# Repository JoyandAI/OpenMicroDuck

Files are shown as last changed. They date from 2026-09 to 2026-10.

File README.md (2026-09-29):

# OpenMicroDuck

**一只完全开源的 25cm 双足机器人**

[English](README_en.md) | [中文](README.md)

---

## 这是什么

OpenMicroDuck 是一个**完全开源**的双足机器人平台：一只 25cm 高、不到 1kg 的小鸭子，15 个自由度，能走、会转头、能发声，可以运行强化学习策略。

本项目受** Hugging Face / Pollen Robotics 的 MicroDuck**的启发——感谢他们把这只小鸭子带到世界面前，让全球开发者看到双足机器人可以如此可爱而触手可及；也感谢他们以开放的态度公开训练生态，让我们得以站在他们的肩膀上继续向前。在 MicroDuck 的基础上，我们将把复现过程的硬件图纸、PCB、BOM、软件栈、训练环境——全部公开发布。

它是我们对"技术平权"的一次实践，也是对 MicroDuck 的致谢。

## 当前进展

飞特 HD-1910 的 BAM 执行器参数已更新到我们 fork 的 [microduck_rl](https://github.com/JoyandAI/microduck_rl)（`develop` 分支），可直接查看 [hd1910 参数目录](https://github.com/JoyandAI/microduck_rl/tree/develop/vendor/bam/bam/params/hd1910)。

### 最新视频

[国产方案调通啦 — MicroDuck 复刻·第三话](https://www.bilibili.com/video/BV1GdYC68Enz/)

飞特 HD-1910 已经调通基本流程，更多动作和流畅控制进一步调校中

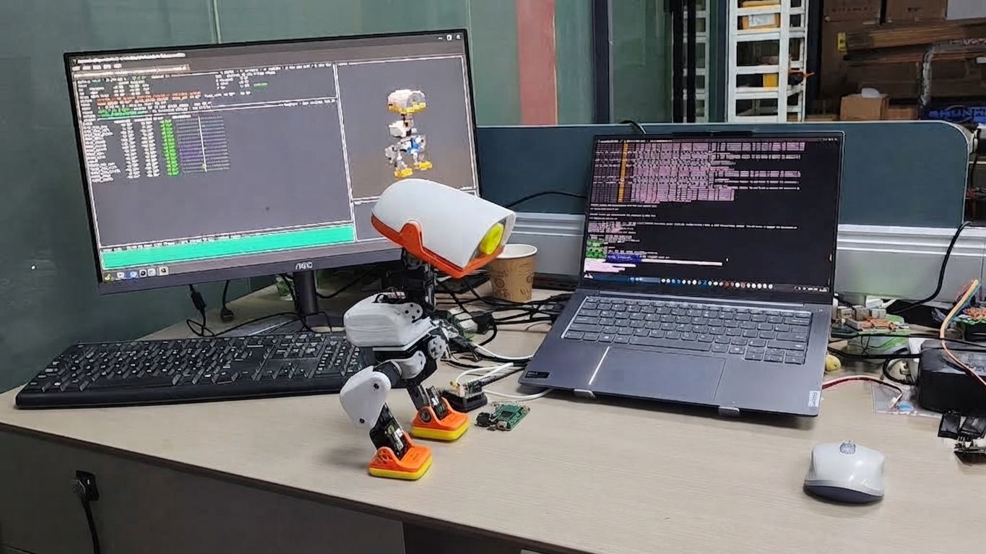
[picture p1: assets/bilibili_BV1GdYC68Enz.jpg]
国产方案调通啦-MicroDuck复刻-第三话


Zero转接HAT板已经回片，测试中...

## 交流群

<p align="center">
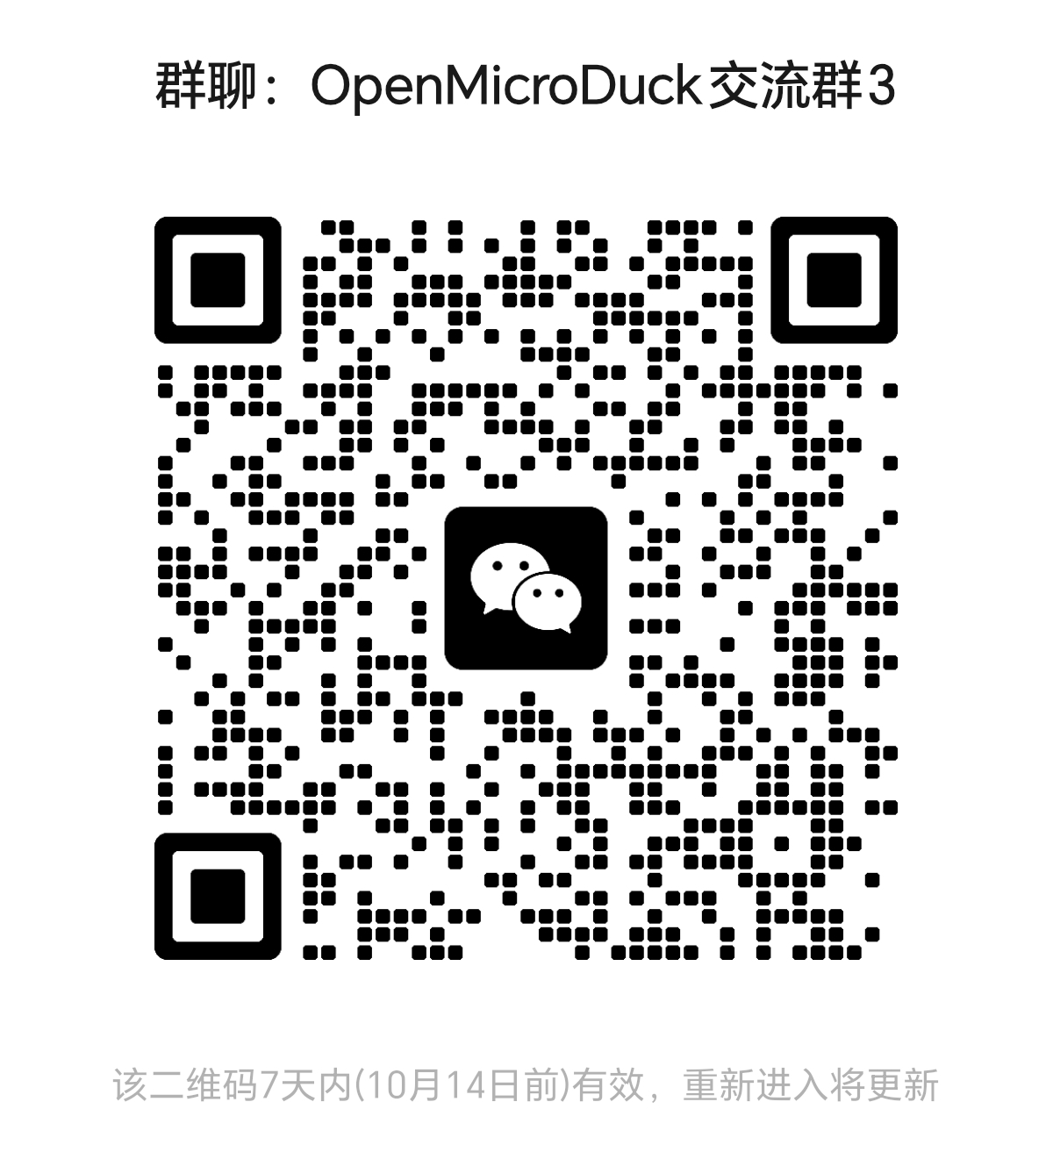
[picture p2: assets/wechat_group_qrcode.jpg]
交流群二维码
  
</p>

## BOM

由于整机集成度比较高，如果完全等所有零配件都ready，再塞进鸭子离线跑，可能要等待比较长的时间。
这里分了两个阶段：

- 第一阶段（桌面调试）：主控和舵机驱动板外置，这样可以由电源适配器供电，主控也可以接显示屏，舵机可由驱动板直接连接PC，方便调试。
- 第二阶段（整机集成）：Zero HAT板和IMU转接板完成之后，再部署已经调试好的模型和软件，完整塞进机器人内部，形成一台完整的整机。

规格、数量、版本差异与结构件清单见 **[docs/bom.md](docs/bom.md)**。

### 桌面调试

| 器件 | 型号 | 规格 | 数量  | 参考单价和链接 |
| ----- | --- | --- | --- | --- |
| 舵机 | **飞特 HD-1910-C001** | 恒力空心杯舵机，4~8.4V，堵转扭矩 12kg·cm | 15  | [118](https://item.taobao.com/item.htm?id=1014620157895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) |
| 主控 | **Radxa ZERO 3W** | RK3566, 2GB RAM，带WiFi, 无eMMC板, 带排针版 | 1 | [309](https://item.taobao.com/item.htm?id=763812025816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) |
| SD卡 | MicroSD/TF卡 | 64GB, A2 | 1 | ~100 |
| IMU模组 | LSM6DSV16X模块 | 支持I2C和SPI接口 | 1 | [49](https://item.taobao.com/item.htm?id=1083871166103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) |
| 摄像头模组 | IMX219摄像头模组 | MIPI FPC排线，500万像素 | 1 | |
| 结构件 | PLA[+TPU] FDM 3D打印  | 有条件的话，脚垫可选用TPU打印 | 1 | - |
| 轴承 | 6700K | 10 x 15 x 3 | 3 | [2](https://item.taobao.com/item.htm?id=1084278550250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) |
| 轴承 | ET2216 | 16 x 22 x 4 | 1 | [3.5](https://item.taobao.com/item.htm?id=1084278550250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) |
| 紧固件 | 螺丝 | M2自攻 | 若干  | |
| 电线 | 特软硅胶线、铁氟龙线 | 30cm | 若干  | |
| 舵机转接线 | | PH2.0转5264 3P转接线（调试用），先用1根PH2.0 3P接驳1根5264 3P线 | 1 | - |
| 麦克风 | | | 2 | |
| 扬声器 | | | 1 | |
| 电池(配重) | 7.4V 3400mAh 2S 锂电池组 | 18650 2串，放电倍率2C，XH2.54 2P公头 | 1 |  [35.8](https://item.taobao.com/item.htm?id=900301752962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) |

### 整机集成

| 器件 | 型号 | 规格 | 数量  | 参考单价和链接 |
| --- | --- | --- | --- | --- |
| 舵机 | **飞特 HD-1910-C001**  | 恒力空心杯舵机，4~8.4V，堵转扭矩 12kg·cm | 15  | [118](https://item.taobao.com/item.htm?id=1014620157895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) |
| 主控 | **Radxa ZERO 3W** | RK3566, 2GB RAM，带WiFi, 无eMMC板, 带排针版 | 1 | [309](https://item.taobao.com/item.htm?id=763812025816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) |
| SD卡 | MicroSD/TF卡 | 64GB, A2 | 1 | ~110 |
| Zero Robot HAT转接板 | | | 1 | |
| IMU_to_servo转接板 | | LSM6DSV16X，带AMP3P-2.0插口 | 1 | |
| 摄像头模组 | IMX219带FPC排线 | 500万像素 | 1 | |
| 结构件 | PLA[+TPU] FDM 3D打印 | 有条件的话，脚垫可选用TPU打印。 | 1 | - |
| 轴承 | 6700K | 10 x 15 x 3 | 3 | [2](https://item.taobao.com/item.htm?id=1084278550250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) |
| 轴承 | ET2216 | 16 x 22 x 4 | 1 | [3.5](https://item.taobao.com/item.htm?id=1084278550250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) |
| 紧固件 | 螺丝 | M2自攻 | 若干  | |
| 麦克风 | | | 2 | |
| 扬声器 | | | 1 | |
| 电池 | 7.4V 3400mAh 2S 锂电池组 | 18650 2串，放电倍率2C，XH2.54 2P公头 | 1 |  [35.8](https://item.taobao.com/item.htm?id=900301752962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) |

### 研发辅助材料

以下是研发调试材料，不是每台机器人必须的BOM

| 器件 | 型号 | 规格 | 数量  | 参考单价和链接 |
| --- | --- | --- | --- | --- |
| 舵机驱动板 | 飞特 URT2串口总线舵机驱动板 | TypeC接口 | 1 | |
| 舵机电源适配器 | 7.5V舵机电源适配器 | 7.5V3A，DC5.5*2.1插头，3C认证 | 1 | - |
| 主控电源适配器 | PD直流电源适配器 | 用TypeC口的PD电源适配器就可以，确认支持5V3A或5V2A | 1 | - |
| 数据线 | USB TypeC->TypeA 或 双头TypeC | 0.5m~1.5m | 1 | |
| MicroHDMI线 | MicroHDMI->HDMI线 | ~1.5m | 1 | |
| 读卡器 | MicroSD卡读卡器 | USB 2.0够用，如果笔记本已经有就不需要了 | 1 | |

## 整机架构

软件与 Microduck 同一条回路：离线 PPO 训出 ONNX，板上 **50 Hz** 执行，契约 **观测 61 维 → 动作 14 维**。硬件换成可公开打样的国产件；换舵机必须重训，官方 ONNX 不能当即插即用步态。

OpenMicroDuck 硬件模块（规划）

选型对照、舵机连线、进程与控制环见 **[docs/README.md](docs/README.md)**（[架构](docs/architecture.md) · [主控](docs/main_controller.md) · [舵机](docs/servo.md)）。

## 路线图

| 里程碑 | 时间 | 目标 |
| --- | --- | --- |
| M1  | 2026-09 | 整机组装，RL 行走验证，桌面调试版确定 |
| M2  | 2026-10 | 整机集成版确定，中英双语教程上线 |
| M3  | 2026-11 ~ | 量产版投产，生态放大：技能包、兼容性持续优化 |

开源项目不拼小批量台数，拼的是复现成功率与开发者体验。每个里程碑公开评审，测试数据与问题清单全量开放。

## 如何参与

任何程度的参与都有意义：

1. **关注** —— Star 本仓库，加入社区（Discord / B 站 / 微信群），见证并传播进展
2. **文档** —— 中英双语教程写作、文档翻译
3. **复现** —— 打印、组装，把公差与干涉问题提 Issue；复现数据是开源硬件最硬的通货
4. **创作** —— 技能包、外观二创、训练管线改进
5. **共建** —— 核心模块 PR，进入维护者委员会，共同决定技术方向

贡献指南见 `CONTRIBUTING.md`（待发布）。

## 为什么做这个项目

**让门槛再低一点。** 双足机器人的核心技术并没有想象中遥远，但一套进口舵机动辄数千元、关键结构闭源、教程零散——把太多人挡在了门外。我们把每个环节拆开、验证、用高性价比的国产供应链重新实现，然后把一切公开：主控只要求 RK3566 同级算力，电池组安全、可拆解，结构件一台 3D 打印机就能做出来。

**让生态再大一点。** 我们希望更多供应链厂商参与进来——舵机、主控、电池、3D 打印与注塑结构件。兼容性矩阵公开，任何厂商的同类器件都可以来适配。竞争发生在开放的标准上，受益的是整个生态。

**让创意再多一点。** 一只鸭子能做什么，不该由我们定义。换一个皮肤甚至换一种形态、写一个新技能、改一套步态、接一颗传感器——我们期待看到更多开发者的二创、以及我们根本想象不到的玩法。你创造的不只是一台机器鸭，而是下一个有意思、有价值产品的起点。

## 许可证

| 内容 | 许可证 |
| --- | --- |
| 硬件图纸、PCB、BOM | CERN-OHL-S |
| 软件栈、训练环境 | Apache-2.0 |
| 教程与文档 | CC BY-SA |

## 致谢

本项目受 Hugging Face / Pollen Robotics 的 MicroDuck启发，并复用了其公开的训练生态。再次感谢 MicroDuck 团队的开创性工作与开放精神——没有他们，就没有这个项目。OpenMicroDuck 是独立的社区开源项目，与 Hugging Face、Pollen Robotics 无隶属关系。

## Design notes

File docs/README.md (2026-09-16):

# OpenMicroDuck 文档

本目录是硬件与软件规划的入口。当前选型：

| 项目  | 当前选择 | 详细文档 |
| --- | --- | --- |
| 架构  | 几何与控制契约对齐 Microduck；供应链换成可公开打样的国产件 | [architecture.md](architecture.md) |
| 主控  | **Radxa ZERO 3W**（RK3566，≥1 GB，有 eMMC 更好） | [main_controller.md](main_controller.md) |
| 舵机  | **飞特 HD-1910-C001** × 15 | [servo.md](servo.md) |
| BOM | 桌面调试版 / 整机集成版器件清单；结构螺丝与 3D 打印件 | [bom.md](bom.md) |

条目索引与外部链接见 [reference.md](reference.md)。

证据分级与各篇正文相同：**官方** / **源码还原** / **规划** / **未定**。本文是摘要，数字与接口以对应长文为准。

---

## 1. 架构 — [architecture.md](architecture.md)

软件与硬件如何拼在一起：策略在哪训练、模型长什么样、板载如何采样 / 推理 / 驱动电机与扬声器。

**软件架构不区分 Microduck 与本仓库。** 两边走同一条 sim-to-real 回路：离线训出 ONNX，板上 50 Hz 闭环执行。差别在执行器品牌、电池、哪些 PCB 开源。

### 软件（通用）

- 训练不在机器人上：`microduck_rl` 用 mjlab（MuJoCo Warp）+ PPO；执行器模型（BAM）和域随机化决定能否上真机。
- 运动策略是 **ONNX**，契约 **观测 61 维 → 动作 14 维 @ 50 Hz**。嘴是第 15 轴，由上层逻辑开合，不进策略。
- 摄像头和 8×8 ToF **不进入**标准行走策略；感知侧只把几十字节特征喂给行为层。
- 板载七个守护进程 + `robotctl`，Unix socket 上 JSON-RPC。**只有** `robotd` **能写电机。**
- 走路在 CPU 上跑 ONNX Runtime；NPU 留给视觉检测，不进平衡环。

### 硬件（规划）

目标：25 cm、15 DoF、50 Hz、61/14；机械图纸、PCB、BOM 按 CERN-OHL-S 发布。

OpenMicroDuck 硬件模块（规划）

| 模块 | 规划 |
| --- | --- |
| 计算主控 | RK3566 同级；当前落地先用 Radxa ZERO 3W，见下文 |
| 舵机 ×15 | 飞特 TTL 半双工、带位置/速度/电流反馈；当前落地选 HD-1910-C001 |
| 机身 IMU | 自制 `imu_to_servo`，挂在舵机总线上，从机 ID 200 |
| 头部 IMU | I²C 辅助模组，**不进** 50 Hz 平衡环 |
| 相机 / ToF | CSI 模组 + 8×8 DToF（I²C） |
| 电池 | 当前用2S 18650电池组7.4V复现 |

换舵机或改质量分布之后，官方 ONNX **不能当即插即用步态**；要在 `microduck_rl` 里按新执行器重训，并保持 `obs[61] → act[14]`。

---

## 2. 主控 — [main_controller.md](main_controller.md)

**当前选择：Radxa ZERO 3W。**

与官方 Microduck 开发栈差异最小：设备树 `compatible = "radxa,zero-3w"`，overlay、NPU 脚本、HAT 针脚都按这块板写过。优先买 **≥1 GB RAM、有 eMMC** 的那档（官方机是 1 GB + 32 GB eMMC）。

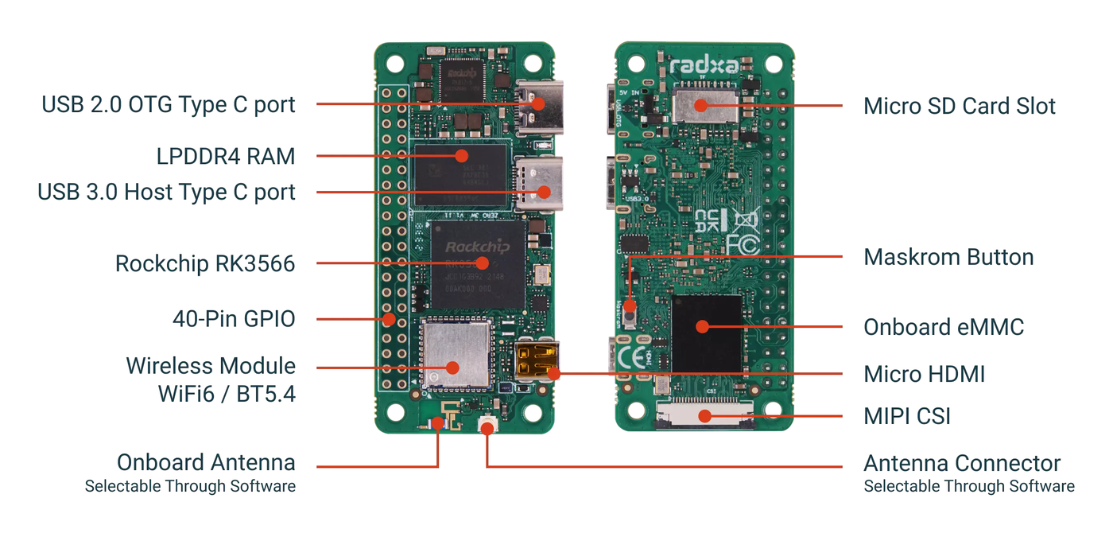
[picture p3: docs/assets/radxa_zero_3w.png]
Radxa ZERO 3W


*图：正反面接口。来源：[Radxa ZERO 3 文档](https://docs.radxa.com/zero/zero3)。*

| 项目 | ZERO 3W |
| --- | --- |
| 尺寸 | 65 mm × 30 mm（Pi Zero 同外形） |
| SoC | RK3566，四核 A55 @ 最高 1.6 GHz |
| AI | NPU 0.8 TOPS（INT8）；走路不用，视觉检测用 |
| 内存 / 存储 | 1–8 GB LPDDR4；可选 eMMC 或 microSD |
| 无线 | Wi-Fi 6 + BT 5.4 |
| 和鸭子相关的口 | UART2 → 舵机总线；I²C3 → ToF / codec；MIPI CSI → 相机；I²S → 喇叭 |

验收三件事：50 Hz 跑完 ORT 且 CPU 有余量；HAT 上同时拿出 UART + I²C + I²S（3.3 V）；有可用 CSI。

同系列 **ZERO 3E** 用网口换掉无线，除非外挂 Wi-Fi / BT，否则不合适。Armbian 默认在 UART2 开 `serial-getty`，不 mask 会占死舵机总线。

详细文档还列了其它 RK3566 模组、CM4 核心板、RK3568、进迭时空 K1 等平替路径；那些是缺货或改载板或升级时的备选，**不是当前默认件**。

---

## 3. 舵机 — [servo.md](servo.md)

**当前选择：飞特 HD-1910-C001**（产品页 / 对照表亦作 HD-1910；外形图文件名为 `HD-1910M-C001`）。

Microduck 运行时按 Dynamixel XL330-M288-T 说话。HD-1910-C001 是飞特为开源小鸭做的预售款：磁编码、恒力、TTL 菊花链，电压 **5–8.4 V**，比 XL330 的 5 V 上限更适合 2S 锂电 / 18650。换型号必须 **重训** 策略。

| 项目 | HD-1910-C001（当前选择） | XL330-M288-T（官方基线） |
| ----- | --- | --- |
| 重量 | 21 ± 2 g | 18 g |
| 尺寸 mm | 34 × 20 × 23 | 20 × 34 × 26 |
| 堵转扭矩  | 12 kg·cm @6V（1.18 N·m） | 0.52 N·m @ 5 V |
| 额定扭矩  | 3.0 kg·cm（0.29 N·m） | 未给 |
| 空载转速  | 110 rpm | 103 rpm @ 5 V |
| 供电 | **4–8.4 V** | 3.7–6.0 V（推荐 5 V） |
| 接口 | AMP2.0-3P | JST 3P TTL |
| 协议 | 飞特 TTL 半双工 | Dynamixel 2.0 |
| 反馈 | 负载 / 位置 / 速度 / 电压 / 电流 / 温度 | 位置 / 速度 / 电流 / PWM / 电压 / 温度 |

总线规划与官方运行时对齐，便于沿用观测布局（嘴仍是策略外的第 15 轴）。板上 UART 与舵机都应跑在 **1 Mbps**；出厂若不是这个波特率，要在初始化里改过去。

### 舵机连线

15 颗 HD-1910-C001 + 机身 IMU 挂在 Zero HAT 引出的同一条 TTL 半双工总线上，菊花链分叉如下。

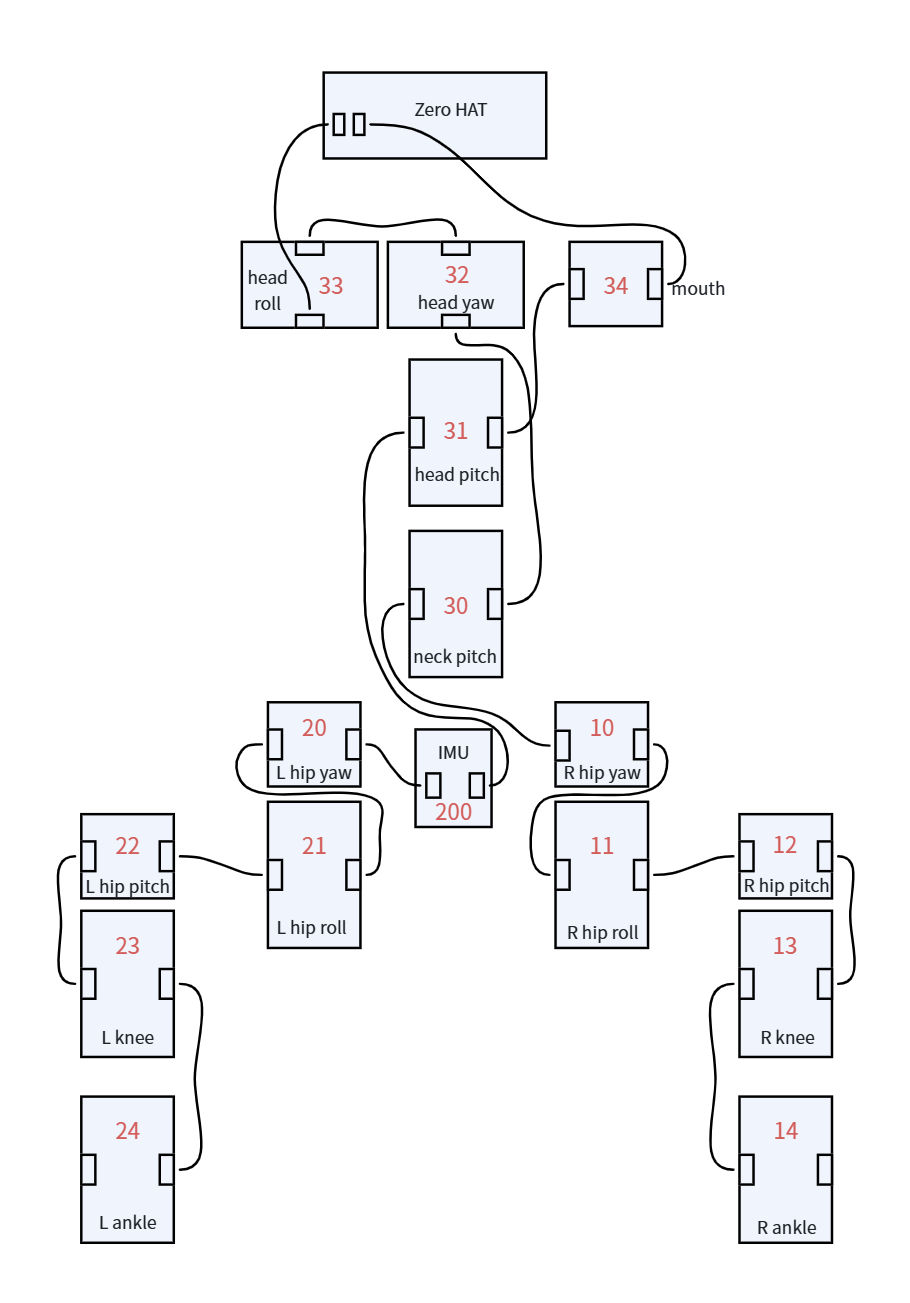
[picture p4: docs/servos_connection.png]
舵机之间的连接关系


```text
Zero HAT
  ├─ 34 mouth
  └─ 33 head_roll → 32 head_yaw → 31 head_pitch → 30 neck_pitch
                                              ├─ 20 L hip yaw → 21 roll → 22 pitch → 23 knee → 24 ankle
                                              ├─ 10 R hip yaw → 11 roll → 12 pitch → 13 knee → 14 ankle
                                              └─ 200 IMU（跨接在左右髋之间）
```

ID 规划：

```text
右腿          10 right_hip_yaw · 11 right_hip_roll · 12 right_hip_pitch · 13 right_knee · 14 right_ankle
左腿          20 left_hip_yaw  · 21 left_hip_roll  · 22 left_hip_pitch  · 23 left_knee  · 24 left_ankle
颈 / 头 / 嘴  30 neck_pitch    · 31 head_pitch     · 32 head_yaw        · 33 head_roll  · 34 mouth
机身 IMU      200
```

宇树 YS-342026-S288、伺泰威 ED330、飞特 HL-2915 等对照见 [servo.md](servo.md) §3；那些是候选，**不是当前默认件**。

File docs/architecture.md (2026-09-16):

# OpenMicroDuck / Microduck 架构

本文整理软件与硬件如何拼在一起：策略在哪训练、模型长什么样、板载如何采样 / 推理 / 驱动电机与扬声器，以及各模块靠什么接口通信。

**软件架构不区分 Microduck 与本仓库规划。** 两边走同一条 sim-to-real 回路：离线训出 ONNX，板上 50 Hz 闭环执行。硬件选型、电源与开源边界不同，见后两节。

证据分级：

| 标记 | 含义 |
| --- | --- |
| **官方** | 产品页、新闻稿，或 `pollen-robotics/microduck` / `microduck_rl` 源码与设计文档 |
| **源码还原** | 运行时写死的设备路径、I²C 地址、寄存器；社区据此还原，非官方 BOM |
| **规划** | 本仓库 README 与规划文档 |
| **未定** | 公开材料互相矛盾，或量产件尚未冻结 |

条目来源见 `[reference.md](reference.md)`。Microduck 机械 / 整机电控并未作为开源硬件发布；HAT 板除外。

---

## 1. 软件架构（通用）

整条链路是「离线训、板上跑、意图进、安全层出」。摄像头图像和 8×8 ToF **不进入**标准行走策略；它们走感知侧，只把几十字节的特征喂给行为层。

软件总览：离线训练与板载执行

### 1.1 训练在哪做

训练不在机器人上。官方仓库 `[microduck_rl](https://github.com/pollen-robotics/microduck_rl)` 用 **mjlab（MuJoCo Warp）+ PPO**。需要 CUDA；没有本地 GPU 时可用 Hugging Face Jobs。

训练里真正决定能否上真机的，是执行器模型而不是视觉：

- **BAM M6**：按 Dynamixel XL330 的电压控制律、反电动势、库仑 / Stribeck / 负载相关摩擦建模。
- **域随机化**：电池电压、负载压降、指令延迟、摩擦系数。
- **回差变体**：每个关节串联 ±1° 齿轮间隙；观测读的是编码器侧（间隙之后），与真机一致。

任务按技能拆开（走、站、起坐、地面拾取、踢球、翻滚、轮滑等），但观测宽度统一，所以运行时可以热切换网络。社区可在 Mac / DGX Spark / Isaac Lab / Genesis 上复训，契约仍是同一套 61 / 14。

仿真网页沙盒（Hugging Face Space）用 MuJoCo WASM + onnxruntime-web，同样 50 Hz 跑真实策略，用来验图、不替代训练。

### 1.2 生成的模型是什么样的

运动策略是 **ONNX**，不是 PyTorch 权重直接上机。导出脚本把观测归一化烘焙进图；手转 checkpoint 会让策略看到未归一化输入。

契约（加载时校验，形状不对则拒绝）：

| | 维数 | 内容 |
| --- | --- | --- |
| 观测  | **61** | `gyro(3)` + `projected_gravity(3)` + `joint_pos(14)` + `joint_vel(14)` + `last_action(14)` + `command(13)` |
| 动作  | **14** | 14 个关节目标；**嘴舵机不在策略里** |
| 频率  | **50 Hz** | 与控制环同一拍 |

`command(13)` = 速度指令 `vx, vy, vyaw`（3）+ 头目标 4 + 身体姿态 6。身体块里 x / y / yaw 在训练中未绑定，标称全零。

嘴（第 15 个舵机）由上层逻辑开合（拾取、合唱口型、特雷门等），动作向量写回 15 槽时该位置保持 0。

官方策略按槽位发布（走、站、起坐、左右踢、地面拾取、翻滚、轮滑等），Hub 仓库一份 `.onnx` + `manifest.json`（观测/动作维、`model_api`、机型兼容性）。板上三个来源填同一个槽：官方组件、社区 Hub、本地路径。

视觉检测是另一类模型：`duck_detector` 训出的 **INT8** `.rknn`（例：YOLO11n 320×320），跑在 RK3566 NPU 上，**不**进 50 Hz 运动环。仓库对外 404，板上路径设计为挂在 `mediad` 里。

音频不是神经网络：每台机器用 SoC 序列号生成确定性「性格」种子，合成一套叫声 bank（chirp / greet / coo 等），不是 TTS。

### 1.3 模型在哪运行

运动 ONNX 在板上由 `robotd` **用 ONNX Runtime** `dlopen` **推理**，每拍一次。ORT 是板级依赖，不打进发布包。

感知在传感器旁边：

| 模型 / 功能 | 进程 | 加速器 |
| --- | --- | --- |
| 运动策略 `.onnx` | `robotd` | CPU（ORT） |
| 鸭子检测 `.rknn` | 设计落在 `mediad` | NPU 0.8 TOPS |
| 麦克风宠物检测（约 20 KB CNN，40-band log-mel） | `robotd` 工作线程 | CPU |

原则：**给控制环的是特征，不是帧。** `robotd` 不订阅 640×480 RGB；它读「球在 (x,y)」「附近有鸭子」这类几十字节、10–30 Hz 的快照。帧卡在 `mediad`，控制环卡不住。

### 1.4 板载进程如何拼在一起

七个守护进程 + 一个 CLI，Unix socket 上 **JSON-RPC 2.0（NDJSON，一行一个对象）**。`systemd` 管生命周期。

板载进程：同一套 API，多种传输

| 进程 | 拥有 | 监听 | 对外 |
| --- | --- | --- | --- |
| `robotd` | 电机、机身 IMU、策略、安全、健康 | `/run/robotd.sock` | Dynamixel（或兼容）总线 |
| `configd`  | Wi-Fi、名字、配对 PIN、手柄绑定 | `/run/configd.sock` | BlueZ / NetworkManager（D-Bus） |
| `updaterd` | 发布包验签、原子切换、回滚 | `/run/updaterd.sock`  | GitHub、`systemctl`、`robot.health` |
| `btd` | 无状态，BLE 门面 | GATT | 转发给 `robotd` / `configd` / `updaterd` |
| `padd` | 无状态，手柄 → 意图 | `/run/padd/pad.sock`  | `robotd` |
| `mediad` | 摄像头、麦克风、编码、WebRTC、远端网关 | TCP `:8080` / `:8443` | 转发给上述服务 |
| `tofd` | 头上 ToF | `/run/tofd/tof.sock`  | HAT 上的 I²C |
| `robotctl` | CLI | — | 所有 socket |

不变量：

1. **只有** `robotd` **能写电机。** 客户端发意图（「这个速度走」「看那边」「坐下」），安全层决定是否执行。
2. `configd` **/** `updaterd` **/** `btd` **在** `robotd` **死掉时仍可用** —— 这是恢复路径。
3. **控制环不对其他服务做同步 RPC。** 跨进程读是 last-value-wins 缓存。
4. **控制面走 socket；视频/音频帧不走 socket。** 真要跨进程传帧，才用 shm / dmabuf。

远端同一套 API、多种传输：BLE（子集）、Unix socket、WebSocket（给 LLM：按需 JPEG，不要 30 fps）、WebRTC datachannel（遥操）。WebRTC 里 `control` 可靠有序，`teleop` 不可靠无序 —— 重传 80 ms 前的摇杆指令比丢掉更糟。

### 1.5 一拍里发生什么（传感器 → 决策 → 电机）

50 Hz，每拍两次总线事务，每秒一次慢采样：

50 Hz 控制环：一拍里的数据流

每秒另读电压 / 温度（寄存器 144–146）。电压是 15 个舵机供电的平均（没有电量计）；温度按关节上报，取最热的那个名字。

摔倒分两层：投影重力 mag 过阈值并 debounce，只用于报告；`limp_fall` 用陀螺预测即将着地，短暂接管关节、卸力、再交回站立策略。摔倒本身不禁止 `enable` / 技能 —— 躺着的时候更需要这些调用能用。

### 1.6 各传感器如何进软件

| 数据 | 谁读 | 频率 | 进运动策略？ |
| --- | --- | --- | --- |
| 关节位置 / 速度 / PWM / 电流 | `robotd` 一次 `sync_read` | 50 Hz | 是（14 关节） |
| 机身 IMU：陀螺 + SFLP 四元数 | 同一趟 `sync_read`（总线 ID 200） | 50 Hz | 是（gyro + projected gravity） |
| 电池电压、舵机温度 | `robotd` 慢采样 | 1 Hz | 否（电压自适应缩放可选） |
| 8×8 ToF | `tofd` → socket 订阅 | ~15 Hz | 否；特雷门、避障、高层行为用 |
| 摄像头 | `mediad`（ISP + MPP H.264） | 默认 720p30 | 否；检测结果作特征 |
| 麦克风 | codec → ALSA；`mediad` 推流，`pet-detect` 另读 | 音频速率 | 否 |
| 头部 IMU | 产品规格有；当前运行时控制环不用 | — | 否 |
| SoC 温度 | `robotd` 读 sysfs | 1 Hz | 否 |

里程计在环内算：足端接触 + IMU 航向。没有磁力计，航向会漂，调用方按相对运动用。

### 1.7 扬声器如何发声

声音不经策略网络。

1. 安装时 `sounds ensure-bank` 用 SoC 序列号生成种子，渲染该机独有的叫声 bank。
2. `robotd` 里 `sound.rs` 拉起一个 `aplay` 子进程；codec 的 PCM 独占，新叫声杀掉旧的。
3. 播放走 ALSA 设备（开发路径上是 `plughw:aic3104`）。喇叭挂在 codec 的 line-out（LEFT_LOP / RIGHT_LOP）。
4. 合唱：多机 BLE 信标选最低 ID 当指挥；`btd` 只搬信标，不决策。合唱会动嘴和头，所以默认关闭。
5. 特雷门：`tofd` 的深度 → 音高 + 嘴开度，50 Hz 环只采样、不等待。

WebRTC 会话可以双向带麦克风和喇叭，用于遥在；本地叫声和远端音频抢同一条 PCM。

---

## 2. 硬件模块架构

两边都是：RK3566 同级 Linux 板 + 扩展板（电源 / 音频 / I²C）+ 一条半双工舵机总线 + 头上的相机 / ToF。差别在执行器品牌、电池、哪些 PCB 开源。

### 2.1 我们规划的架构（OpenMicroDuck）

目标：几何与控制契约对齐 Microduck（25 cm、15 DoF、50 Hz、61/14），供应链换成可公开打样、可替代的国产件。机械图纸、PCB、BOM 按 CERN-OHL-S 发布。

规格（规划，未冻结）：

| 项目  | 规划 |
| --- | --- |
| 整机  | 25 cm / ≤1 kg |
| 自由度 | 15（腿 5×2 + 头颈 4 + 鸭嘴 1） |
| 舵机  | 15 × **Feetech 协议平替**（TTL 半双工、带位置/速度反馈） |
| 主控  | **RK3566 同级**（不绑定某一款模块，兼容性矩阵另发） |
| 电池  | **可拆 18650 电池组** 2S 7.4V, 3S 12V |
| 结构  | 3D 打印（FDM / 光固化）+ 钣金 |
| 控制  | 50 Hz 板载策略环；训练仍用 MuJoCo / PPO |

OpenMicroDuck 硬件模块（规划）

#### 模块与接口（规划）

| 模块 | 规划形态 | 物理接口 | 协议 | 备注 |
| --- | --- | --- | --- | --- |
| 计算主控 | RK3566 同级 SBC | 40-pin、CSI、UART、USB-C | Linux 外设 | 不绑定 Radxa；要能跑 50 Hz ORT + 可选推流 |
| 舵机 ×15 | Feetech 平替 | 3 线：GND / 电源 / DATA | 厂家 TTL 总线（与 Dynamixel 类似的半双工包） | 换执行器必须 **重训** 策略；官方 ONNX 不能当 bit-exact 用 |
| 机身 IMU | `imu_to_servo` 自制板 | 挂在舵机总线上 | 规划对齐官方从机：ID 200、1 Mbps、寄存器 124 起 12 字节（陀螺 i16 + 四元数 fp16） | MCU + LSM6DSV16X（SFLP）+ 半双工 PHY；控制环不在主机上做融合 |
| 头部 IMU | 小 I²C 模组 | 4 针：GND / 3V3 / SDA / SCL | I²C ≤400 kHz | **不进平衡环**；与 ToF 共总线，注意地址 |
| 图像传感器  | CSI 摄像头模组 | MIPI CSI（控制常走 I²C `0x10` 一类） | CSI-2 + I²C | 具体传感器未钉死；软件侧按「感知在 `mediad`」接 |
| DToF | 8×8 多区 ToF | Qwiic / Stemma 类 3.3 V I²C | I²C，常见地址 `0x29` | VL53L5CX / L8CX 一类；`tofd` 发布矩阵 |
| 麦克风 | MEMS，经 codec 或板载 | I²S 数据 + I²C 控制 | ALSA | 可与官方 HAT 路线兼容，或换国产 codec |
| 扬声器 | 小喇叭 | codec line-out / 功放 | I²S → 模拟 | `aplay` 播预渲染 bank |
| 电源 | 18650 可拆组 | HAT 作配电 | — | 与官方 NP-F550 不同；需自管充电、过放、舵机供电轨 |

舵机 ID 规划与官方运行时对齐，便于沿用观测布局（嘴仍是策略外的第 15 轴）：

```text
右腿          10 right_hip_yaw · 11 right_hip_roll · 12 right_hip_pitch · 13 right_knee · 14 right_ankle
左腿          20 left_hip_yaw  · 21 left_hip_roll  · 22 left_hip_pitch  · 23 left_knee  · 24 left_ankle
颈 / 头 / 嘴  30 neck_pitch    · 31 head_pitch     · 32 head_yaw        · 33 head_roll  · 34 mouth
机身 IMU      200
```

##### 桌面调试阶段
桌面调试阶段的硬件连接关系图
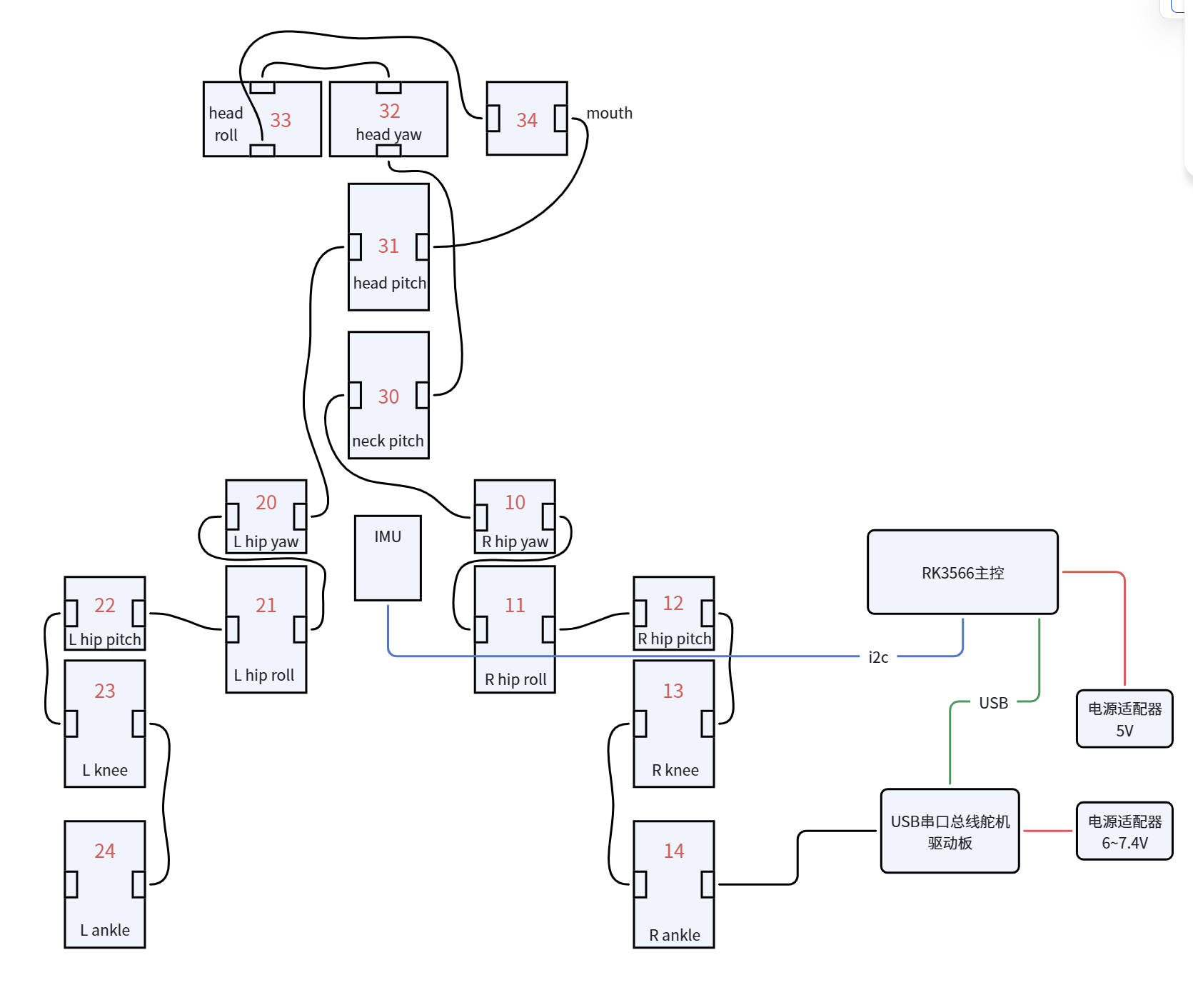
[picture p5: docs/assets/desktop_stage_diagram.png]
桌面调试版硬件连接关系


##### 整机集成阶段
整机集成阶段的硬件连接关系图
整机集成版舵机之间的连接关系

HAT 需要至少三件事：舵机半双工方向电路、电池配电、I²C/I²S 外设。官方 `[elec_RPI_Robot_HAT](https://github.com/pollen-robotics/elec_RPI_Robot_HAT)` 已开源且标明可驱动 Dynamixel **或 Feetech**（线序可能要改），可作第一版参考，再按 18650 与国产件重画。

与官方栈的关系：主控同级、总线从机行为对齐时，可直接跑 Apache-2.0 的 `robotd` 一族。Feetech 寄存器 / 波特率 / 力矩曲线不同，则要在 `RobotIo` 下加驱动，并用 `microduck_rl` 按新 BAM（或实测执行器）重训。

---

### 2.2 推测的 Microduck 架构

产品规格只钉到「RK3566、15 电机、相机、LiDAR、双 IMU」。下面到芯片 / 连接器这一层，来自 **公开运行时、设备树、HAT 开源仓** 的还原，**不是** Pollen 发布的量产 BOM。量产前仍可能改。尚未有可核对的零售机拆解。

整机（官方）：高 25 cm、宽 14 cm、<800 g；15 DoF；50 Hz 策略环；电池 NP-F550 2600 mAh；Wi-Fi + 蓝牙；NFC 双天线（头 + 喙，控制器未公开）。

Microduck 硬件模块（源码还原，非官方 BOM）

#### 模块、接口、协议

| 模块 | 推测 / 还原型号 | 接口 | 协议 | 证据 |
| --- | --- | --- | --- | --- |
| 计算主控 | **Radxa Zero 3W**（RK3566，四核 A55 + Mali-G52 + NPU 0.8 TOPS） | CSI、40-pin、UART2、板载 Wi-Fi/BT | Linux | 设备树 `compatible = "radxa,zero-3w"`；产品规格钉 SoC / 1G+32G |
| 舵机 ×15 | **ROBOTIS Dynamixel XL330**（社区多指向 M288-T 一类） | 3 线 TTL：GND / VDD / DATA | **Protocol 2.0，1 Mbps** | `robotd` 总线文档；`rustypot` 寄存器表 |
| 半双工 PHY | 在 HAT 上 | UART TX/RX → 单线 DATA | 硬件自动换向（源码无方向 GPIO） | HAT README：TTL 与 485 都做了 |
| 机身 IMU | **ST LSM6DSV16X** 在自制 `imu_to_dxl` v2 | 与舵机同一 UART | DXL 从机 **ID 200**；`sync_read` 地址 124、12 字节 | `duck-control` IMU 代码。板子原理图 **未开源** |
| HAT 上第二 IMU | **Bosch BMI088** | I²C `0x19` / `0x68` | I²C | 焊着，源码写 unused / dormant |
| 头部 IMU | 产品规格「头 + 身体各一」 | 未公开 | 未进入当前 `robotd` 控制环 | 官方规格 vs 源码「One IMU, one code path」—— **未对齐** |
| 图像传感器 | **Sony IMX219**（Pi Camera v2 路径） | MIPI CSI + I²C `0x10` | CSI-2；1080p30 传感器模式，ISP 缩到 720p30 | `mediad` / 设备树。量产镜头 **未冻结**（新闻稿） |
| DToF | **VL53L5CX 或 VL53L8CX**（8×8） | HAT Stemma J5，I²C `0x29` | I²C，上电要灌约 90 KB 固件 | `tofd`；两代芯片源码都支持，量产哪颗 **未钉** |
| 音频 codec | **TI TLV320AIC3104** | I²C `0x18` 控制 + **I²S3** 数据；MCLK 12 MHz | I²C + I²S，ALSA 卡名 `aic3104` | 设备树 overlay |
| 麦克风 | HAT 板载 MEMS，走 Mic3R | 模拟 → codec PGA | — | 具体料号未公开 |
| 扬声器 | 接 codec LOP | 模拟 | — | 料号未公开 |
| NFC | 双天线：头 + 喙 | 未公开 | 未公开 | 仅产品规格；运行时源码无提及 |
| 电池 | **Sony NP-F550**，2S，标称 7.2 V | 经 HAT 配电 | 无电量计；电压 = 舵机回报的总线电压 | 官方规格 + 运行时注释。零售 XL330 额定 3.7–6.0 V，与 2S 直供 **如何匹配尚未被量产机证实** |

舵机 ID（官方控制环）：

```text
imu_to_dxl    200
右腿          10 right_hip_yaw · 11 right_hip_roll · 12 right_hip_pitch · 13 right_knee · 14 right_ankle
左腿          20 left_hip_yaw  · 21 left_hip_roll  · 22 left_hip_pitch  · 23 left_knee  · 24 left_ankle
颈 / 头 / 嘴  30 neck_pitch    · 31 head_pitch     · 32 head_yaw        · 33 head_roll  · 34 mouth
```

`imu_to_dxl` 12 字节块（与 15 个舵机同一趟读，主机不做融合）：

| 偏移 | 内容 |
| ---- | --- |
| 0–5  | 陀螺 x/y/z，`i16` LE，±500 dps |
| 6–11 | SFLP 四元数 x/y/z，IEEE binary16；`w` 在主机用 `√(1−x²−y²−z²)` 补 |

HAT 上 I²C3 占用 40-pin 的 3/5。Radxa 原厂把同一控制器的 M1 给了 USB-C PD（FUSB302）；官方 overlay 改到 M0 后 **失去 PD 协商**，普通 5 V 充电仍可用。Armbian 默认在 UART2 开 `serial-getty`，不 mask 就会把整条舵机总线占死。

#### 和「双 IMU」的关系

新闻稿写身体、头部各一颗 IMU。源码控制环只认总线上的 LSM6DSV16X。HAT 的 BMI088 明确休眠。头部那颗更像交互 / 头姿辅助，或量产与开发板不一致。复刻平衡环时，**不要**把第二颗 IMU 当成 50 Hz 观测的一部分。

#### 开源边界（官方立场）

| 开源 | 未作为开源硬件发布 |
| --- | --- |
| 板载软件（Apache-2.0） | 可编辑机械 CAD、整机装配文档  |
| `microduck_rl` 与 ONNX 策略 | `imu_to_dxl` 原理图  |
| 仿真 MJCF + 训练用 STL | 量产 BOM、线束图 |
| **RPI Robot HAT**（KiCad / Gerber / BOM） | NFC 控制器；部分传感器量产料号 |

---

## 3. 对照摘要

| | OpenMicroDuck（规划） | Microduck（公开材料 + 源码还原） |
| --- | --- | --- |
| 软件 | 同一套：PPO 离线训 → ONNX → 板上 50 Hz `robotd` | 同左（官方实现） |
| 主控 | RK3566 **同级**，不绑模块 | 产品：RK3566；开发板还原为 Radxa Zero 3W |
| 舵机 | Feetech 平替 | Dynamixel XL330 |
| 机身 IMU | 自制 `imu_to_servo`，行为对齐 ID 200 | 同结构，原理图未开源 |
| 头部 IMU | I²C 辅助模组，不进控制环 | 规格有；运行时未用 |
| ToF / 相机 | 同角色（I²C 8×8 + CSI） | VL53L5/8CX + IMX219 路径 |
| 电池 | 18650 可拆组 | NP-F550 |
| 硬件开源 | 图纸 / PCB / BOM 全公开 | 仅 HAT + 软件；整机不称开源硬件 |

换舵机或改质量分布之后，官方 9 个 ONNX 不能当即插即用步态；要在 `microduck_rl` 里按新执行器重训，并保持 `obs[61] → act[14]`，才能继续热切换技能。

---

## 4. 主要来源

- 官方运行时架构：[https://github.com/pollen-robotics/microduck/blob/main/docs/design/architecture.md](https://github.com/pollen-robotics/microduck/blob/main/docs/design/architecture.md)
- 控制环与总线：[https://github.com/pollen-robotics/microduck/blob/main/docs/design/robotd-design.md](https://github.com/pollen-robotics/microduck/blob/main/docs/design/robotd-design.md)
- 策略通道：[https://github.com/pollen-robotics/microduck/blob/main/docs/design/policy-channel-design.md](https://github.com/pollen-robotics/microduck/blob/main/docs/design/policy-channel-design.md)
- 训练：[https://github.com/pollen-robotics/microduck_rl](https://github.com/pollen-robotics/microduck_rl)
- HAT：[https://github.com/pollen-robotics/elec_RPI_Robot_HAT](https://github.com/pollen-robotics/elec_RPI_Robot_HAT)
- 产品规格：[https://pollen-robotics.com/microduck/press-kit/](https://pollen-robotics.com/microduck/press-kit/)
- 条目索引：`[reference.md](reference.md)`

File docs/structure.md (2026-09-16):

# OpenMicroDuck 结构说明

> 优化结构版本：**v0.1**

本仓库内的结构经过修改以适配舵机 **HD1910**，与之结构相同的还有 **HL2909** 舵机。同时优化了部分结构，让它更适合 3D 打印、也更加稳定。

## 打印与装配

- 使用 Bambu Studio 直接打印已经摆盘好的 `cad/openmicroduck.3mf` 即可。
- 装配参考文件：`cad/openmicroduck-assembly-opt.stl`。
- 散件文件：`cad/psrts`。
- BOM 表（含结构件与电器件）：[bom.md](bom.md)

## 结构差异（舵机）

MicroDuck 上使用的舵机大部分要拆掉副舵盘来安装，且使用 XL330舵机，与本仓库兼容的舵机在拆掉副舵盘后有明显的结构差异：

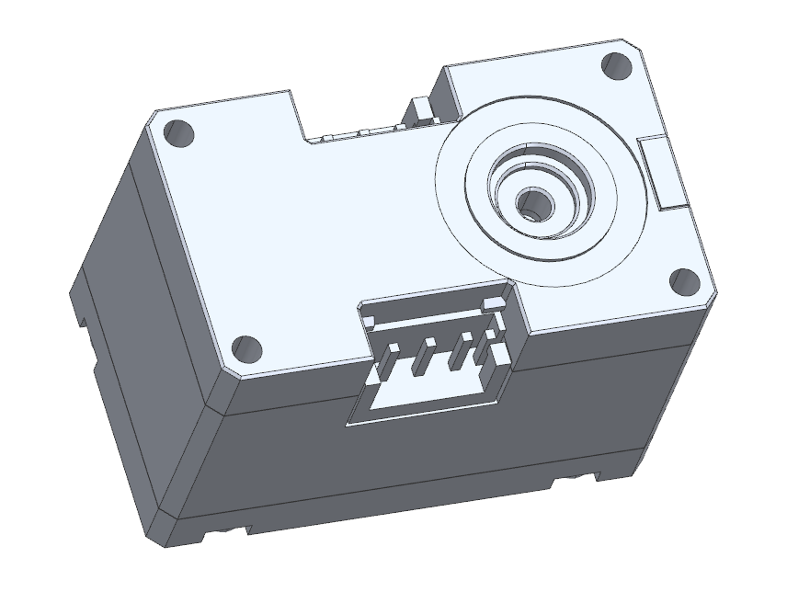
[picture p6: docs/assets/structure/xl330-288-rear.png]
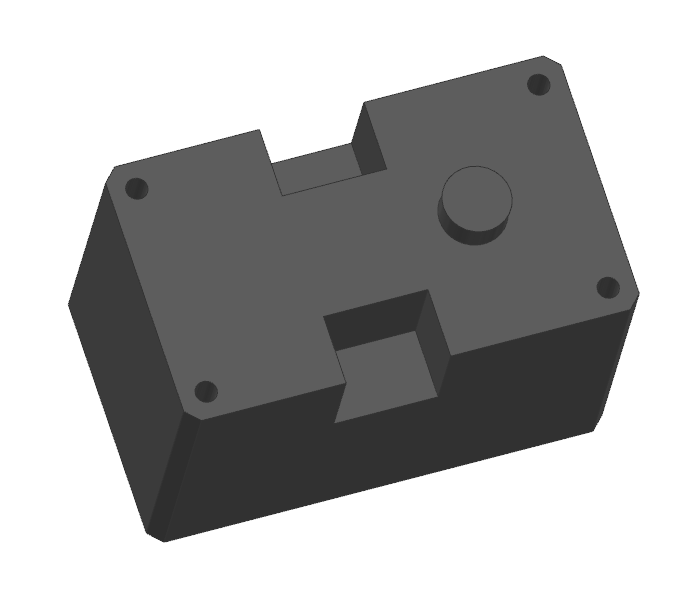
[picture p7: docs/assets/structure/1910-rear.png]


XL330 在拆掉副舵盘后是**凹下去**的，而 HD1910 是**突起的**——本仓库大部分结构变化主要由这一点引起。

## 优化内容

### 头部

- **优化前**：HD1910 的突起部分会与后面的螺丝柱发生干涉（下图）。

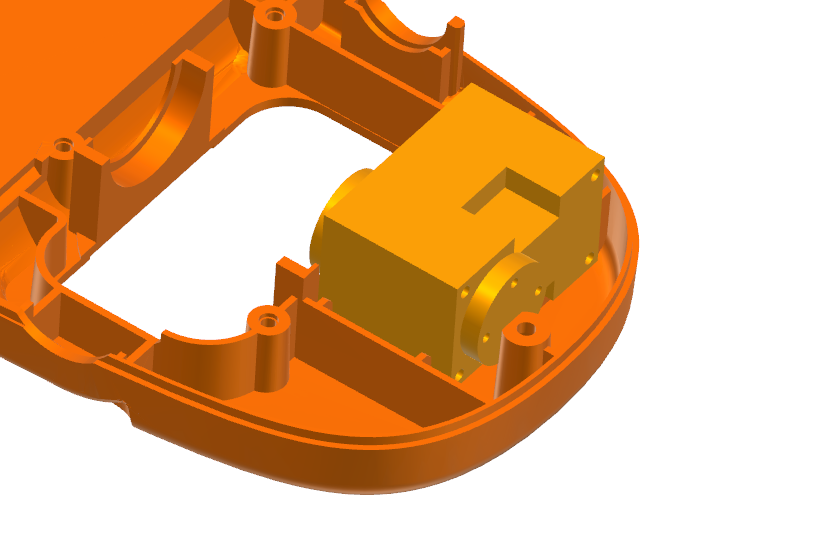
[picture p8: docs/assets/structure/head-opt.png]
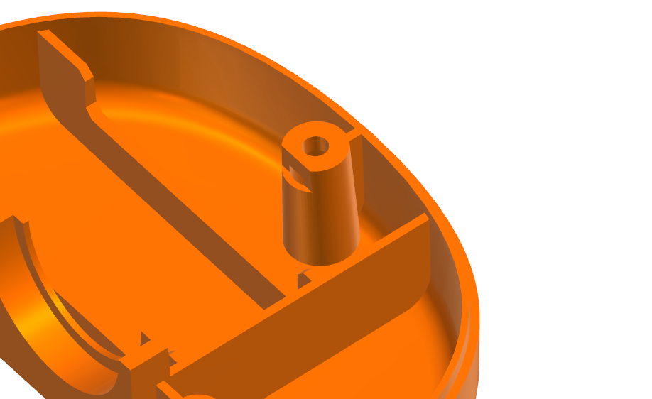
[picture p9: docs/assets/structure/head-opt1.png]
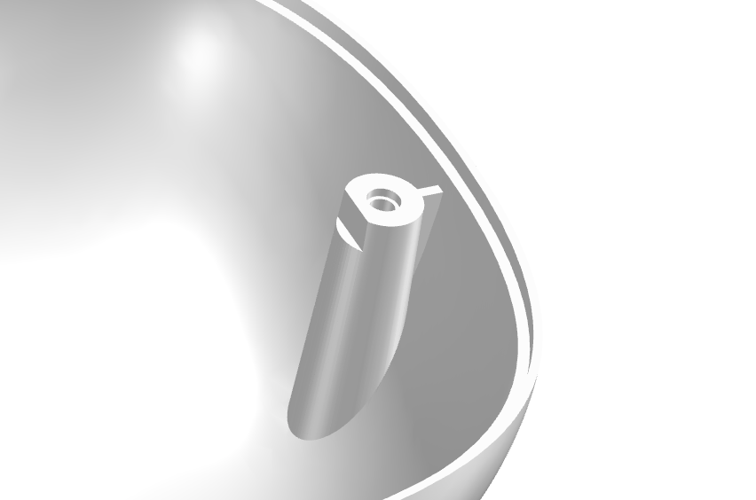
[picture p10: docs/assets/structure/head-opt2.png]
 - **优化后**：切掉螺丝柱一部分消除干涉，不影响螺丝安装。 

### 下巴

由于 3D 打印精度的缘故，下巴内的 `jaw_soft` 会与 `bottom_head_shell` 摩擦，导致开嘴困难甚至开不了嘴。已将 `jaw_soft` 缩短消除影响。

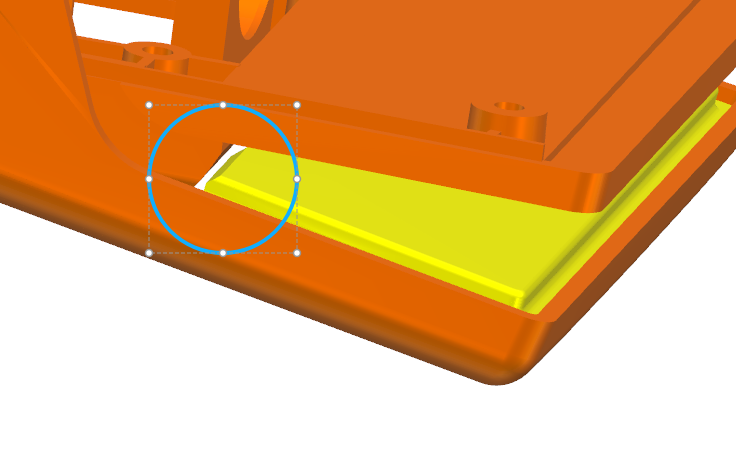
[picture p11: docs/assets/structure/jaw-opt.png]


### 脖子

加厚脖子连接件。原版仅 1 mm 厚，3D 打印风险较高。

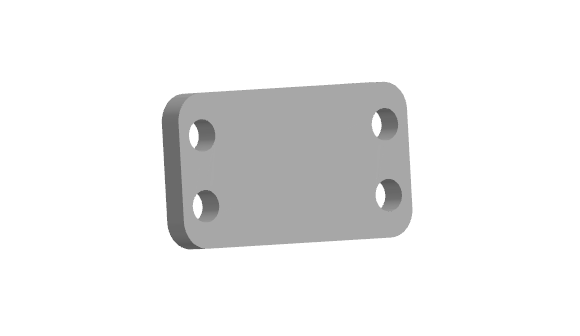
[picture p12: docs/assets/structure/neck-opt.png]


### 躯干

**优化前**：`trunk_base` 结构薄弱，不利于 3D 打印，且舵机只有 2 个孔固定，更加脆弱。

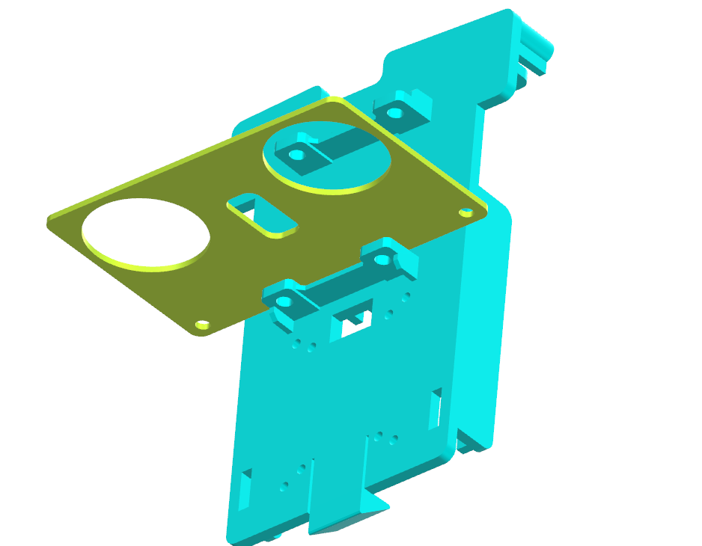
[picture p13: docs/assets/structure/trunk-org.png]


**优化后**：

- 增厚 `trunk_base`；
- 每个舵机都有 3 个孔固定；
- 优化 `power_support` 固定方式，以舵机为基准固定；
- 修改陀螺仪固定孔，兼容 LSM6DSX 陀螺仪。

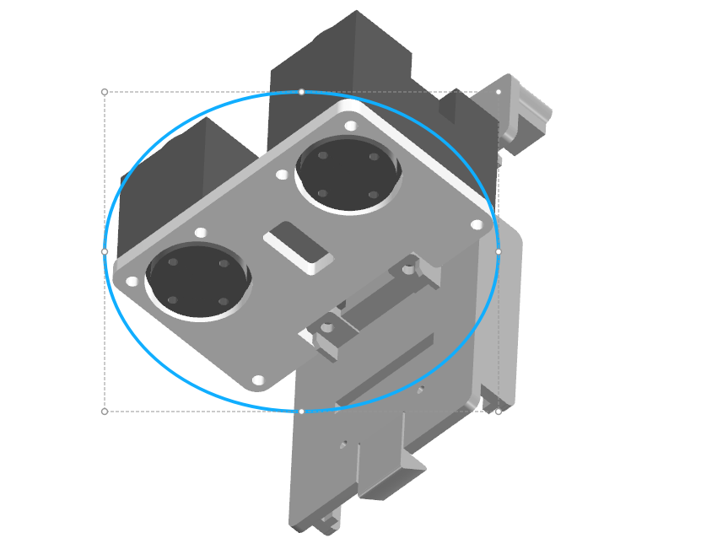
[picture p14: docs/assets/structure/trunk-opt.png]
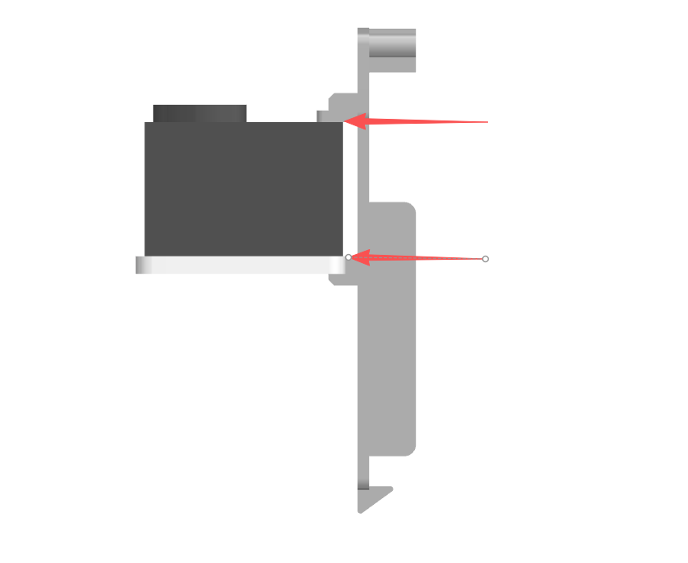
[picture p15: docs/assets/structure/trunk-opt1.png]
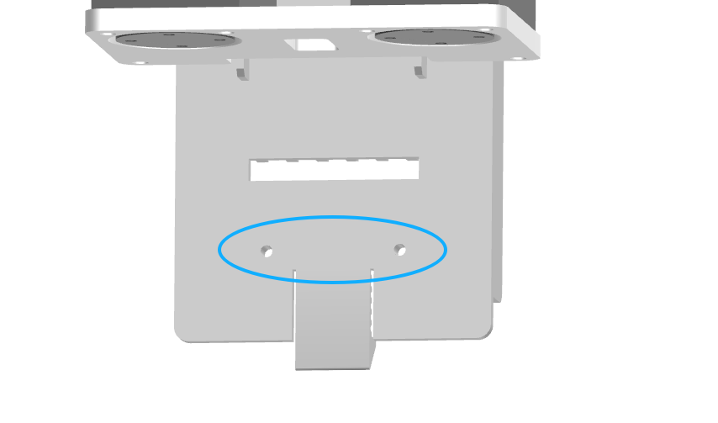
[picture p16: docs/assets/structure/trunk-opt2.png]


### 胯部

**优化前**：yaw 部分由两个零件锁定舵机，3D 打印后实测稳定性较差，且不与 HD1910 兼容；连接的螺丝孔位还导致 `trunk_base` 舵机前方不能拧螺丝。

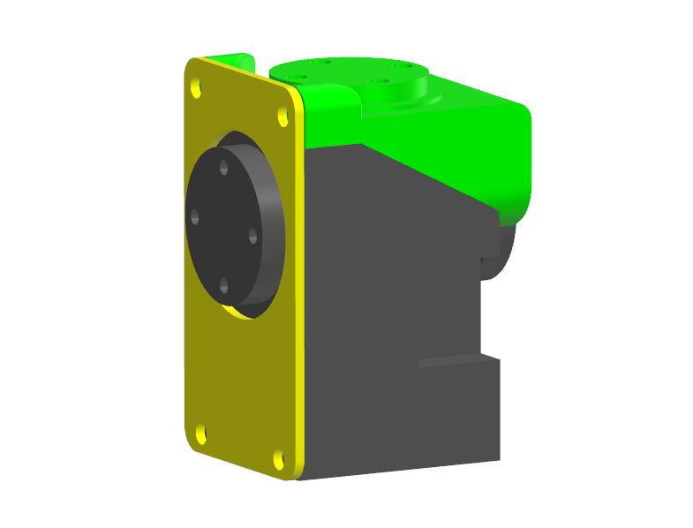
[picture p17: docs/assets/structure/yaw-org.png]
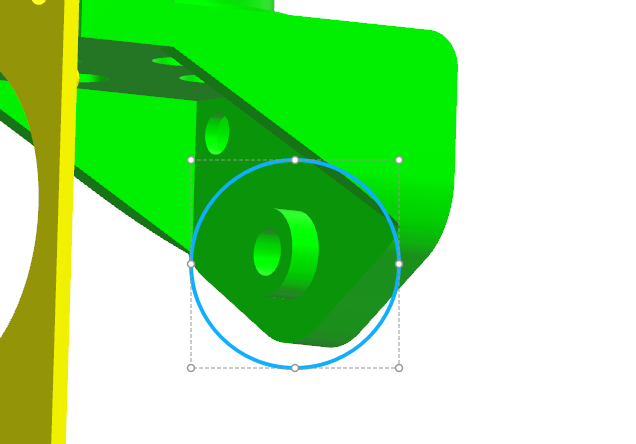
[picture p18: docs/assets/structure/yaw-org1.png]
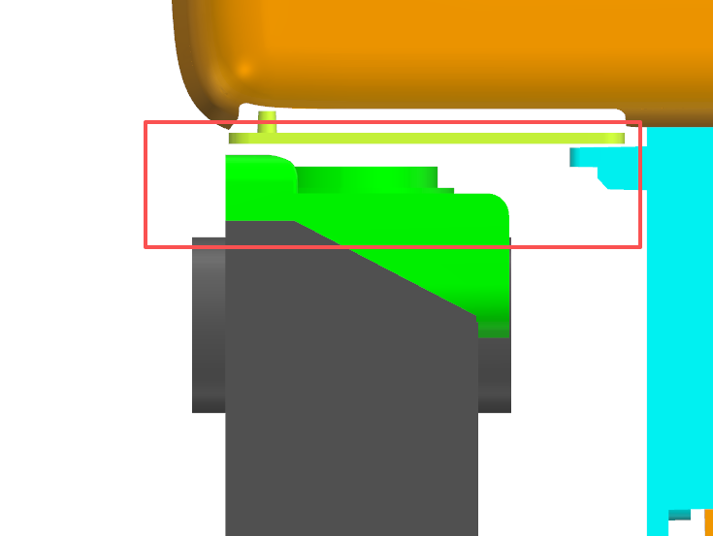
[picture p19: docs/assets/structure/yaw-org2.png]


**优化后**：

- yaw 改为一体式，结构简单稳固；
- 为上述 `trunk_base` 的舵机留出拧螺丝的位置。

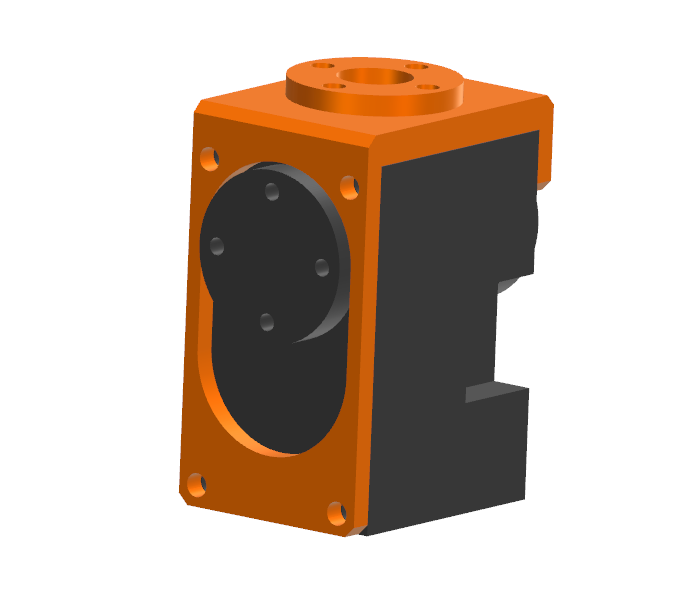
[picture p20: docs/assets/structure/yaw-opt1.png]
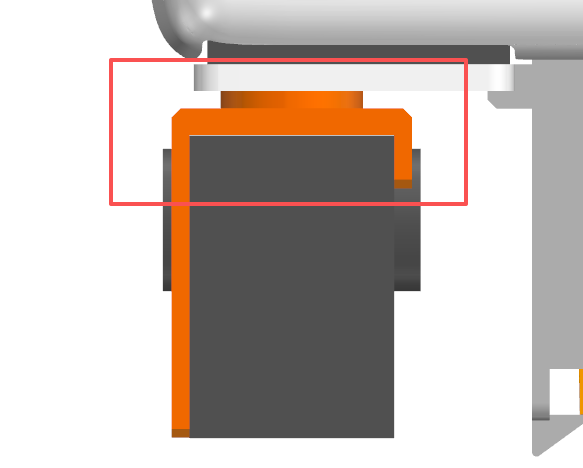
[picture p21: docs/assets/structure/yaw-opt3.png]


### 腿部

- **upper_leg**：
  - 加厚了 `upper_leg_rigidity_plate`；
  - 修改 `upper_leg` 使其兼容 HD1910：去掉两个定位柱，让线路更好走、更容易安装。

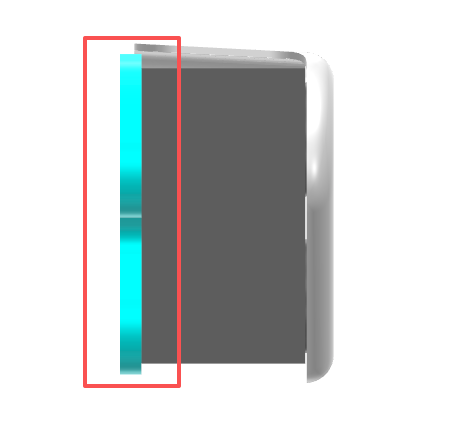
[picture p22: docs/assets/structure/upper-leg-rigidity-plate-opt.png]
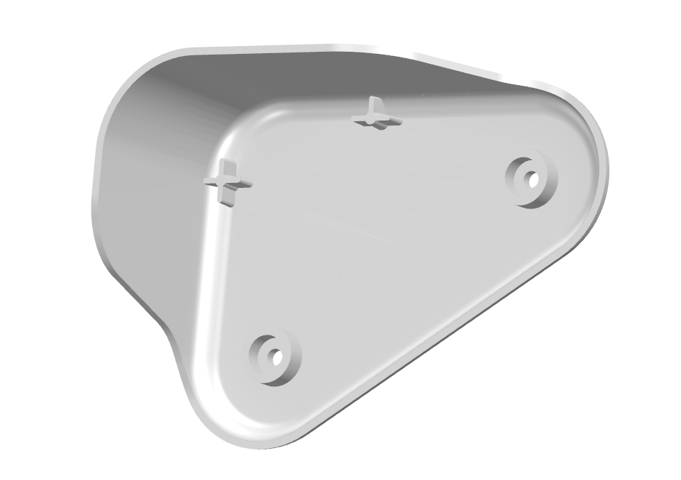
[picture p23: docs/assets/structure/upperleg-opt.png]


- **leg**：优化使其兼容 HD1910。

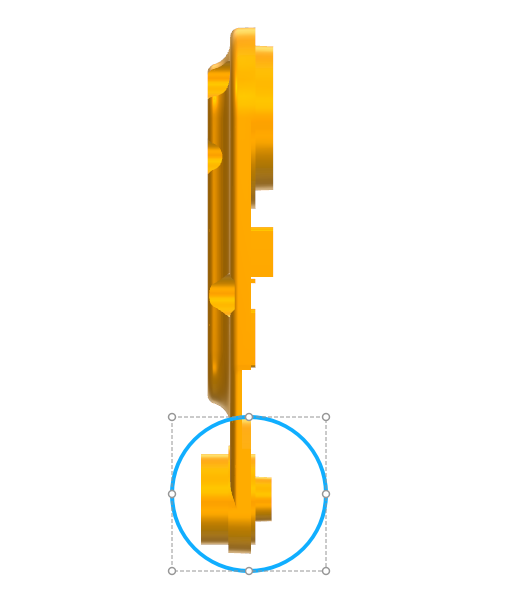
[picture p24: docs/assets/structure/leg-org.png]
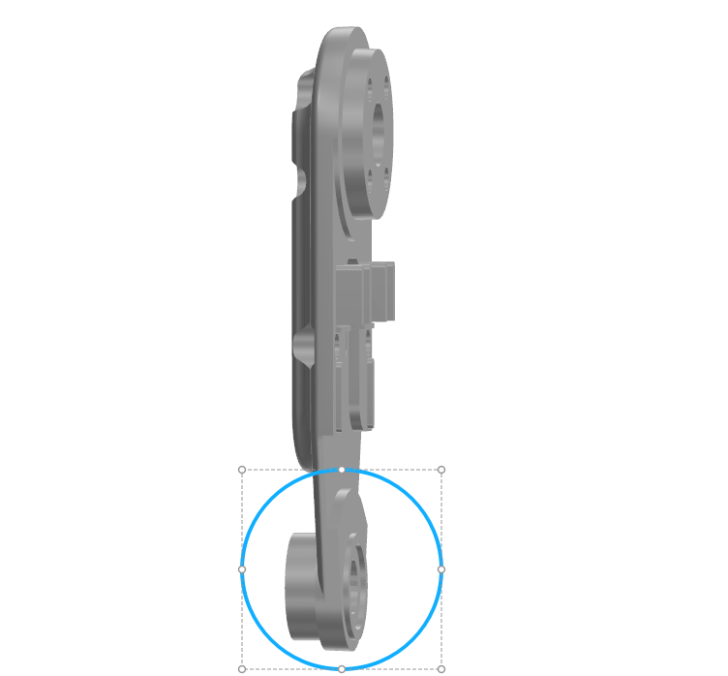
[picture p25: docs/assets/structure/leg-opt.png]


### 脚（ankle）

**优化前**：轴承从内部安装，再装到腿部模组上——除非这个部件很软，否则不论是 XL330 还是 HD1910 都很难安装到腿上；且底部是平的，会与舵机干涉，导致脚无法转动。

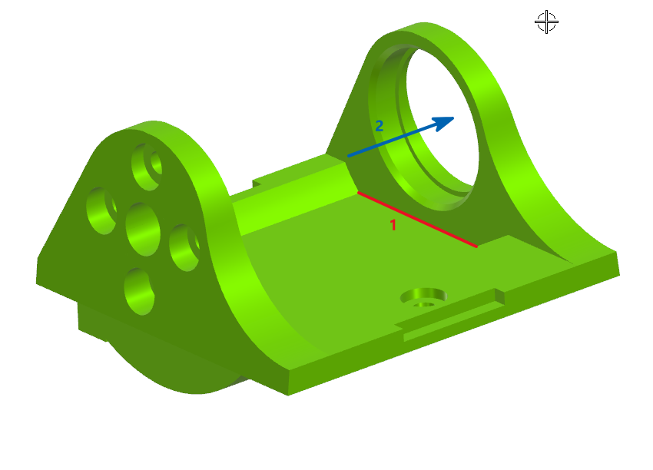
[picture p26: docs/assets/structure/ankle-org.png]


**优化后**：

- 将内部改成圆弧结构，让脚能顺利转动；
- 增加一个弹筋结构：
  1. 让 ankle 更顺利地安装到腿部模组（Leg module）上；
  2. 通过卡扣结构从外侧能更好地安装轴承；
  3. 通过 foot 限位卡扣，极大缩小轴承松脱风险。



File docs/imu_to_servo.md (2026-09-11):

PCBA设计工程路径

- `imu_to_servo`（Dynamixel EH 2.5 mm + 飞特 PH 2.0 mm 双口）：
  `E:\SynologySync\02-personal\10-创业\99-卓研智趣\MicroDuck\imu转接板-设计\imu_to_servo`
- `imu_to_ft`（只留飞特 PH 2.0 mm 左右双口）：
  `E:\SynologySync\02-personal\10-创业\99-卓研智趣\MicroDuck\imu转接板-设计\imu_to_ft`

考虑未来可扩展性，兼容电压 6~12V

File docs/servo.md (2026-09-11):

# 舵机选型

本文说明 OpenMicroDuck 的舵机选型逻辑：Microduck 实际用的是哪颗、它提供什么能力、按什么标准找平替。

证据分级与 `[architecture.md](architecture.md)` 相同：

| 标记 | 含义 |
| --- | --- |
| **官方** | 产品规格、厂商手册，或 `pollen-robotics/microduck` 源码与设计文档 |
| **源码还原** | 运行时写死的寄存器、波特率、总线事务；社区据此还原，非官方 BOM |
| **规划** | 本仓库的选型原则，尚未冻结兼容性矩阵 |
| **未定** | 公开材料互相矛盾，预售件尚未给全参数，或零售价随渠道波动 |

舵机是整机成本与 sim-to-real 的第一瓶颈：15 颗执行器决定结构能不能原样装上、50 Hz 环能不能读全状态、以及官方 ONNX 能不能当 bit-exact 用。换型号必须 **重训** 策略，见 `[architecture.md](architecture.md)` §3。

---

## 1. Microduck 用的是什么

产品规格钉的是 **15 个电机**；运行时总线按 **ROBOTIS Dynamixel XL330** 说话（**官方**：`[robotd-design.md](https://github.com/pollen-robotics/microduck/blob/main/docs/design/robotd-design.md)`、`[rustypot](https://github.com/pollen-robotics/rustypot)` 寄存器表）。规格没有写 M288 / M077 这一档 SKU。

减速比、堵转扭矩、以及训练里的 **BAM M6** 执行器模型（按 XL330 电压控制律建模）与 **XL330-M288** 对齐，而不是高速低扭的 M077（77:1，堵转约 M288 的 1/3）。本文按 **XL330-M288-T** 记录；若量产改用同壳其它减速比，几何能装、控制契约对不上。

后缀 `-T` 是 TTL 半双工；没有 RS-485 的 `-W` 变体。手册：[XL330-M288](https://docs.robotis.com/docs/dxl/model_reference/x_series/xl_series/xl330-m288/)。

### 1.1 规格（官方手册）

| 项目 | XL330-M288-T |
| --- | --- |
| 重量 | **18 g** |
| 尺寸（W × H × D） | **20.0 × 34.0 × 26.0 mm** |
| 减速比 | **288.4 : 1** |
| 编码器 | 12-bit 绝对式磁编码（ams AS5601），4096 pulse/rev |
| 堵转扭矩 | 0.42 N·m @ 3.7 V（1.11 A） **0.52 N·m @ 5.0 V（1.47 A）** 0.60 N·m @ 6.0 V（1.74 A）  |
| 额定扭矩 | 手册与商店页 **未给**（Continuous Operation 栏为 —） |
| 空载转速 | 76 rpm @ 3.7 V 103 rpm @ 5.0 V 123 rpm @ 6.0 V |
| 空载电流 | 商店页：**0.15 A @ 5.0 V**（e-Manual 规格表未单列） |
| 待机电流 | **17 mA**（商店页另写 15 mA） |
| 供电 | **3.7 ~ 6.0 V**（推荐 **5.0 V**） |
| 最高通讯带宽 | 硬件 **9 600 bps ~ 4 Mbps**（波特率表另有 4.5 Mbps 档） |
| Microduck 实际波特率 | **1 Mbps**（见 §4） |
| 接口 | TTL 3P 菊花链（随包 **Robot Cable-X3P**，JST–JST）；逻辑 **3.3 V，5 V 兼容** |
| 线序 | 与常见 DYNAMIXEL 3P 相同：GND / VDD / DATA |
| 通信协议 | **Dynamixel Protocol 2.0**；半双工异步，8N1 |
| 恒力相关模式 | **电流控制（Operating Mode 0）**；**电流限制的位置控制（Mode 5，Current-based Position Control）** |
| 出厂默认模式 | Mode **3**（普通位置控制） |
| 反馈 | 位置、速度、电流、PWM、轨迹、温度、输入电压、错误状态 |
| 外壳 / 齿轮 | 工程塑料 |
| 零售价（2026-09） | Robotics 韩国店 **$23.90**；美国店 **$27.49**；国内授权渠道约 **¥95–¥238**（随 SKU / 含税波动） |

15 颗按韩国店牌价约 **$360**，是整机 BOM 里最贵的一块。这是找平替的直接原因。

### 1.2 为什么是这颗，而不只是「能转的舵机」

XL330-M288 在这个尺寸里同时给了三件对 RL 双足要紧的东西：

1. **磁编码 + 总线状态回报。** 50 Hz 环要的不是「转到大概某个角」，而是编码器侧的位置 / 速度，外加 PWM 与电流。官方一拍 `sync_read` 读寄存器 124–136（PWM、电流、速度、位置）；电压、温度在 144–146，每秒另读一次（**官方**：`[robotd-design.md](https://github.com/pollen-robotics/microduck/blob/main/docs/design/robotd-design.md)`）。没有这些反馈，61 维观测拼不出来，BAM 也标定不了。
2. **电流环 / 电流限制的位置环（恒力）。** Mode 0 只跟电流（力矩）；Mode 5 跟位置，同时用 `Goal Current` 把力矩顶住。摔倒卸力、落地冲击、鸭嘴夹东西、人工拖关节，都不能靠「位置 PID 死顶」。恒力把输出扭矩变成可设的上限，齿轮和结构才活得过接触。
3. **轻、小、菊花链。** 18 g、20×34×26 mm、双 3P TTL，15 颗加 `imu_to_dxl` 挂同一根半双工线。HAT 上只要一套 UART 换向电路。

电流、力矩、温度各自进不同层，不是装饰寄存器：

- **电流 / PWM：** 每拍进观测；也是过载、堵转、接线故障的第一现场。BAM M6 按电压控制律与反电动势建模，没有电流就没有这条 sim-to-real 缝。
- **力矩（由电流 × 力矩常数估计，或厂家直接给负载寄存器）：** 安全层用来限幅；策略不直接输出力矩，但真机接触力必须看得到。
- **温度：** 1 Hz 慢采样，**按关节上报、取最热的那个名字**。下蹲时膝盖远比鸭嘴热；平均 15 颗会把快过热的那颗藏起来。`shutdown` 掩码在过热、过载、输入电压故障时锁存（运行时写成 `52`）。

默认 Mode 3 也能走位置环。`robotd` 启动校正写的是 `return_delay_time`、`baud_rate`、`pwm_slope`、`shutdown`，**没有**把 Operating Mode 改成 5。所以「量产环已经跑在恒力位置模式」目前只能标 **未定**；选型仍要求平替 **具备** 编码恒力（电流环或电流限制的位置环），因为卸力、接触和 BAM 都依赖这条能力。

---

## 2. 选型思路（规划）

尚未做兼容性矩阵。平替按下面六条筛，**可以只先满足机械与电气，再补协议**；协议不兼容不是否决项。

| # | 原则 | 含义 |
| --- | --- | --- |
| a | **结构能装上** | 外形、安装孔、轴齿、出线方向与 XL330 同档，尽量不改腿 / 头壳体 |
| b | **类型相同** | 必须是 **磁编码 + 恒力（电流 / 电流限制位置）** 总线舵机，不是 PWM 航模舵机 |
| c | **电气、扭矩、重量相近**  | 电压、堵转 / 额定、空载转速、质量分布接近，才谈得上复现步态；差一档就要重训 |
| d | **接口与出线方向一致** | 3 线 TTL、GND / 电源 / DATA 线序、插头与出线方向少改电路和结构 |
| e | **协议可以改软件** | Dynamixel / 飞特 / 宇树自定义 **大多互不兼容**；改 `RobotIo` 驱动的成本小于改模具 |
| f | **质量可控，价格足够便宜** | 15 颗是乘法；在可追溯批次与寿命测试的前提下压价 |

电压不同 **必须改供电器件**：电池组串数、HAT 上的舵机轨、MOSFET / 电流容量、连接器额定，都不能沿用 XL330 的 5 V 假设。Microduck 电池是 NP-F550（2S，标称 7.2 V），零售 XL330 上限 6.0 V，两者如何匹配 **尚未被量产机证实**（`[architecture.md](architecture.md)` §2.2）。OpenMicroDuck 规划 18650 可拆组，轨电压跟选定舵机走。

换执行器之后，官方 9 个 ONNX **不能当即插即用步态**。要在 `microduck_rl` 里按新 BAM（或实测）重训，并保持 `obs[61] → act[14]`。

---

## 3. 目前可选的平替

对照基线是 XL330-M288-T。候选来自本仓库 `hardware_spec/servo/` 与厂商公开页；**不是**已冻结的采购清单。

### 3.1 型号说明

1. **Feetech HD-1910-C001**（外形图亦作 HD-1910M-C001）
  飞特为开源小鸭做的串行总线舵机。电气与协议以规格书 A/0（2026-09-07）为准：`hardware_spec/servo/HD-1910-C001串型规格书-20260907.pdf`。工作电压 **4–8.4 V**，电气表给 4.8 / **6** / 7.4 V 三点；封面按 6 V / 12 kg 标定。外形图：`hardware_spec/servo/HD-1910M-C001-drawing-20260902.pdf`。
2. **Unitree YS-342026-S288**
  宇树无刷数字舵机塑料壳档，**12.6 V** 推荐，外形 **20 × 34 × 26 mm** 与 XL330 同尺寸、同 288.35:1 减速比。[产品页](https://www.unitree.com/cn/DigitalServo)。同系列 J288 是金属齿 / 铝壳 / 最高 25.2 V，更重更贵，不作为默认平替。
3. **伺泰威 ED330**（预售）
  规格图见 `[hardware_spec/servo/ED330-servo-spec.png](../hardware_spec/servo/ED330-servo-spec.png)`。外形与 HD-1910 同档（约 34×20×23 mm），但规格图不分电压，额定负载写成 **0.8 kg·cm**（HD-1910 在 6 V 是 3 kg·cm），不能当成同一颗。协议、波特率、恒力模式规格图 **未给**。淘宝链：[预售页](https://item.taobao.com/item.htm?id=1081660456822)。
4. **Feetech HL-2909-C001 / HL-2915-C002**
  用户侧说明 **HL-2915-C002 为曾用名**。仓库规格书封面型号是 **HL-2915-C002**（A/0，2026-02-27），正文未出现 2909 的独立参数表，下表按这份 12 V 规格书写。文件：`hardware_spec/servo/HL-2915-C002_HL-2909-C001串型规格书-20260227.pdf`。

### 3.2 参数对照

扭矩、空载转速、电流以 **6 V** 为对照点（1 kg·cm ≈ 0.098 N·m）。XL330 上限即 6.0 V；HD-1910 规格书给了 4.8 / 6 / 7.4 V 三点，表内取 **6 V**。S288 最低 6.4 V、HL-2915 额定 12 V，规格书没有 6 V 工况，这两列保留其额定电压并写明，避免和 6 V 混读。空格表示该来源没写。

| 舵机型号 | XL330-M288-T | HD-1910-C001 | YS-342026-S288 | ED330 | HL-2915-C002 |
| --- | --- | --- | --- | --- | --- |
| 证据 | **官方** 手册 | 飞特规格书 A/0，2026-09-07 | **官方** 产品页 | 厂商规格图 | 飞特规格书 A/0 |
| 重量 | 18 g | 21 ± 2 g | 19.5 g | 22.5 ± 2 g | 22.5 ± 2 g |
| 尺寸 mm | 20 × 34 × 23含舵盘（20 × 34 × 29） | 20 × 34 × 23含舵盘（20 × 34 × 29） | **20 × 34 × 26** | 34.4 × 20 × 23 | 34 × 20 × 23 |
| 减速比 | 288.4 : 1 | 320 : 1 | 288.35 : 1 | （规格图未给） | 320 : 1 |
| 对照电压 | **6.0 V**（上限） | **6 V**（另有 4.8 / 7.4 V） | 12 V（最低 6.4 V，**无 6 V 点**） | 未给分压点（范围 5–8.4 V） | 12 V（范围 9–14 V，**无 6 V 点**） |
| 堵转扭矩 | ≈ 6.1 kg·cm（0.60 N·m）@ 6 V | **12 kg·cm**（1.18 N·m）@ 6 V | 0.6 N·m @ 12 V | 10 kg·cm（0.98 N·m） | 8.9 kg·cm（0.87 N·m）@ 12 V |
| 额定扭矩 | 未给 | **3 kg·cm**（0.29 N·m）@ 6 V | 未给 | **0.8 kg·cm**（0.078 N·m） | 2.9 kg·cm（0.28 N·m，约 1/3 堵转）@ 12 V |
| 空载转速 | **123 rpm** @ 6 V | **92 rpm** @ 6 V | 157 rpm @ 12 V | 110 rpm | 77 rpm @ 12 V |
| 供电 | 3.7–6.0 V（推荐 5 V） | **4–8.4 V** | 6.4–12.6 V（推荐 **12.6 V**） | **5–8.4 V** | **9–14 V**（额定 12 V） |
| 待机 / 空载 / 额定 / 堵转电流 | 17 mA / 未给 @ 6 V / — / **1.74 A** @ 6 V | **20 mA / ≤180 mA / 690 mA / 1.6 A** @ 6 V | 50 mA / 0.27 A / — / — @ 12 V | 21 / 140 / 500 / 1800 mA | 42 / 140 / 200 / 600 mA @ 12 V |
| **最高**波特率 | 4 Mbps | **1 Mbps** | **6 Mbps** | 未给 | **1 Mbps** |
| 接口 | JST 3P TTL，双口菊花链；1 GND / 2 VDD / 3 DATA | AMP2.0-3P：**1 Signal / 2 Vcc / 3 GND** | TTL 多点总线 | 规格图未给针序 | AMP-3：**1 GND / 2 Vcc / 3 Signal** |
| 协议 | Dynamixel 2.0 | 半双工 8N1，飞特数字包 | **宇树自定义** | 未给 | 半双工 8N1，飞特包 |
| 恒力 | Mode 0 / Mode 5 | 模式 2 恒流；默认模式 4 为 PD 位置（规格书写 Sim2Real） | 混合模式：力矩 + 刚度 / 阻尼 | 规格图未写 | 模式 2 恒流；地址 44 恒力输出 |
| 反馈 | 位置 / 速度 / 电流 / 电压 / 温度 / PWM | 位置 / 速度 / 电流 / 电压 / 温度 / 负载 | 转子力矩与角度、输出端角度、角速度、温度、电压 | 未给 | 负载 / 位置 / 速度 / 电压 / 电流 / 温度 |
| 编码器 | 12-bit 绝对，输出端 | 12-bit 磁编码 | **双绝对值**（转子 15-bit + 输出端） | 未给 | 12-bit 磁编码 |
| 电机 / 齿轮 | 有芯 / 工程塑料 | 空心杯 / 金属齿 | 无刷 / 工程塑料 | 未给 | 有芯 / 金属齿 |
| ID 范围 | 0–252 | 0–253（出厂 ID 1） | **0–14** | 未给 | 0–253（出厂 ID 1） |
| 零售价 | $23.90–$27.49 / ¥95–¥238 | 预售，**¥123** | 官方店 **$29**（另有学生价档） | 预售，**未定** | 公开价 **未定** |

HD-1910 在 4.8 / 6 / 7.4 V 的完整电气点（规格书 §5）：空载 73 / **92** / 113 rpm；堵转 9 / **12** / 15 kg·cm；额定 2.2 / **3** / 3.7 kg·cm；堵转电流 1.2 / **1.6** / 2 A。Kt = 7.5 kg·cm/A。

读这张表时先看三列，而不是只看堵转：

- **结构：** S288 与 XL330 同外形、同减速比，机械上最省事；飞特 / ED330 是 34×20×23、深度少约 3 mm，但HD1910来说，其实是测量部位不一样，孔距要拿实物核。
- **6 V 扭矩：** 同一电压下 HD-1910 堵转 12 kg·cm，约 XL330（6.1 kg·cm）的两倍；额定 3 kg·cm。S288 的 0.6 N·m 与 XL330 在 6 V 的堵转同量级，但那是 **12 V** 工况。
- **电气：** HD-1910 走 4–8.4 V，HAT 电源改动小于 12 V 的 S288 / HL-2915。上 12 V 就要改电池串数或 DC-DC、以及 15 路堵转电流预算。
- **针序：** HD-1910 是 **1=Signal / 3=GND**，与 Dynamixel 和 HL-2915 的 **1=GND / 3=Signal** 相反，不能按 XL330 线序直插。
- **协议与 ID：** 宇树协议要新驱动；**ID 仅 0–14** 盖不住官方 ID 图（腿 10–14 / 20–24，头 30–34，IMU 200）。除非厂家开放更大 ID，否则软件侧要改编址或拆总线。飞特改寄存器映射的成本相对小。

ED330 规格图仍写堵转 10 kg·cm、额定 **0.8 kg·cm**，且不分电压；HD-1910 在 6 V 已是堵转 12 kg·cm、额定 3 kg·cm。不要把 ED330 当 HD-1910 的第二货源。

### 3.3 电压不同时要改什么

| 舵机轨 | 代表型号 | HAT / 电池上至少要动的 |
| --- | --- | --- |
| ~5 V（3.7–6.0） | XL330-M288 | 基线；与 2S 直供是否降压 **未定** |
| 4–8.4 V | HD-1910、ED330 | 按 2S 锂电或 NP-F550 一类设计；核对过压保护阈值（HD-1910 规格书过压阈 10 V） |
| 12 V 级 | S288、HL-2915  | 电池串数或升压、舵机轨 MOSFET、连接器与铜箔过流、`imu_to_dxl` 取电是否还从总线来  |

总线电流一般比会单个电机的堵转电流大，但肯定不会是所有电机同时堵转，一般比所有电机的额定电流之和还要小，毕竟不是所有电机都同时工作在额定负载。

---

## 4. Microduck 实际通信速率：1 Mbps

硬件最高 4 Mbps **不是** 运行时用的速度。板上 UART 与舵机 EEPROM 都设置为 **1 000 000 bps**。当然4 Mbps为未来更高级的应用打开可能性。

### 4.1 主机口打开就是 1 Mbps

`[robotd-design.md](https://github.com/pollen-robotics/microduck/blob/main/docs/design/robotd-design.md)` §1.1 把总线画死为：

```text
/dev/ttyS2 · 1 Mbps · Dynamixel protocol v2
```

15 个舵机 + `imu_to_dxl`（ID 200）共用这一口。这是官方设计文档，不是社区推测。

### 4.2 启动时把舵机寄存器写成「3」

同一份文档 §2.1：`check_and_fix_config` 在启动时断言并纠正 EEPROM：

`return_delay_time=0`，`baud_rate=3`，`pwm_slope=255`，`shutdown=52`。

XL330 手册 Baud Rate(8) 对照表（**官方**）：

| 寄存器值 | 波特率 |
| --- | --- |
| 0 | 9 600 |
| 1（出厂默认） | **57 600** |
| 2 | 115 200 |
| **3** | **1 000 000** |
| 4 | 2 000 000 |
| 5 | 3 000 000 |
| 6 | 4 000 000 |
| 7 | 4 500 000 |

因此 `baud_rate=3` **就是 1 Mbps**。出厂默认是 57.6 kbps，不是 1 Mbps；换一颗没初始化过的 XL330 却用 1 Mbps 去扫，会表现为「总线空的」。运行时把寄存器改到 3，和打开 `/dev/ttyS2` 的 1 Mbps 对齐。

`return_delay_time=0` 与波特率是配套的：出厂 250 → 每设备 500 µs 换向，16 个设备约 8 ms，占 20 ms 拍预算的 40%。这不改变比特率，但决定 1 Mbps 够不够用。

### 4.3 对平替的含义

50 Hz、每拍两次总线事务（再加每秒一次慢采样），在 1 Mbps 半双工上是算过的。平替若默认不是 1 Mbps，要在初始化里改到 **至少 1 Mbps**（或接受降频控制环）。飞特 HL 规格书出厂默认已是 1 Mbps；宇树硬件到 6 Mbps，但自定义协议要自己算一拍字节数。标称「最高 4 Mbps」却把 15 颗丢在 115 200 上，环会直接塌。

---

## 5. 主要来源

- XL330-M288 手册：[https://docs.robotis.com/docs/dxl/model_reference/x_series/xl_series/xl330-m288/](https://docs.robotis.com/docs/dxl/model_reference/x_series/xl_series/xl330-m288/)
- ROBOTIS 商店规格（空载电流、连续扭矩栏）：[韩国店 XL330-M288-T](https://en.robotis.com/shop_en/item.php?it_id=902-0163-000) · [美国店](https://www.robotis.us/dynamixel-xl330-m288-t/)
- 控制环与总线寄存器：[robotd-design.md](https://github.com/pollen-robotics/microduck/blob/main/docs/design/robotd-design.md)
- 板级架构：`[architecture.md](architecture.md)` §1.5、§2.2
- 宇树 S288：[https://www.unitree.com/cn/DigitalServo](https://www.unitree.com/cn/DigitalServo) · [官方店](https://shop.unitree.com/products/brushless-digital-servo)
- 飞特 HL-2915-C002 规格书：`hardware_spec/servo/HL-2915-C002_HL-2909-C001串型规格书-20260227.pdf`
- 飞特 HD-1910-C001 规格书 A/0（2026-09-07）：`hardware_spec/servo/HD-1910-C001串型规格书-20260907.pdf`
- 飞特 HD-1910 外形图：`hardware_spec/servo/HD-1910M-C001-drawing-20260902.pdf`
- 伺泰威 ED330 规格图：`hardware_spec/servo/ED330-servo-spec.png`
- 训练执行器模型：`[microduck_rl](https://github.com/pollen-robotics/microduck_rl)` BAM M6（XL330 电压控制律）

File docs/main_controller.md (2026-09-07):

# 主控选型

本文说明 OpenMicroDuck 的主控选型逻辑，并对照 Microduck 实际用的计算板、SoC 能提供什么、按什么标准找平替。

证据分级与 `[architecture.md](architecture.md)` 相同：

| 标记 | 含义 |
| --- | --- |
| **官方** | 产品规格、芯片手册、板厂文档，或 `pollen-robotics/microduck` 源码与设计文档 |
| **源码还原** | 设备树、运行时写死的路径与板级脚本 |
| **规划** | 本仓库的选型原则，尚未冻结兼容性矩阵 |
| **未定** | 公开材料互相矛盾，或量产件尚未冻结 |

NPU 相关只引用 **Pollen / Hugging Face 官方仓** 能交叉核对的内容；走路策略以 Hub 上的 `.onnx` 为准。见 §5。

---

## 1. 主控选型（规划）

尚未做兼容性矩阵。当前倾向：

| 序号 | 选择 | 原因 |
| --- | --- | --- |
| 1 | 能买到的 **Radxa ZERO 3W**（≥1 GB，有 eMMC 更好） | 与官方栈差异最小 |
| 2 | 其它 **RK3566** Zero 模组，或 **CM4 兼容核心板**（如 Radxa CM3） | 同族 NPU 与相机；载板反正要重画 |
| 3 | **RK3568** 开发板（不限外形） | 先把 `robotd` / `mediad` / RKNN 在同族芯片上跑通 |
| 4 | **进迭时空 K1** 开发板（不限外形） | RISC-V 八核、AI 2.0 TOPS；要重编 riscv64 栈，并核功耗 / 散热 |
| 5 | **Pi Zero 2W** / 原版 **Pi CM4** | 机械资料熟；RAM 与 NPU 要按能力降级预期 |

最快的办法是 **直接买 Radxa ZERO 3W**，而且尽量靠近官方那档 1 GB + 32 GB eMMC：设备树、overlay、NPU 脚本、HAT 针脚都已经按这块板写过。但这块板现在常缺货、溢价。长远看，OpenMicroDuck **不把某一 SKU 写进规范**。能接近，就可以做方案。接近分两条，可以只满足一条，最好两条都沾边：

1. **外形足够小**：能塞进头或身体。Zero（约 65×30 mm）和 **CM4 兼容核心板**（约 55×40 mm）都够小。HAT / 转接板反正要重画，不必死守 40-pin Zero 针脚。
2. **SoC 性能接近**：四核 A55 同级（或更强）即可，**不绑定 aarch64**；要有可用的板载 AI 加速（RKNN 或同级）、CSI 和足够 RAM。RISC-V 如进迭时空 K1 也是一个选项，见 §7。

40-pin 或 CM4 座都只保证机械上能接。UART / I²C 落在哪根脚、设备树 overlay、CSI 针脚定义，每家板都要单独核。官方 HAT 标明可驱动 Dynamixel **或 Feetech**，并不等于任意核心板插上就能跑。

验收可以先问三件事：

1. 能否在 50 Hz 跑完 ORT，且 CPU 还有余量给总线和安全层。
2. 载板（40-pin 或 CM4 座）上能否同时拿出 **UART（舵机）+ I²C（ToF / 头 IMU）+ I²S（喇叭）**，电压 3.3 V。
3. 是否有可用的 CSI（或接受 USB 相机，那就要改 `mediad`）。

**NPU（或同级的板载 AI 算力）是视觉等 AI 功能的必须，不是强化学习走路的门槛。** 官方步态是 ONNX，在 CPU 上用 ONNX Runtime 跑；鸭子检测一类感知在官方栈里走 RKNN。换 SoC 可以换加速栈，但不能没有这块算力。

---

## 2. Microduck 用的是什么

产品规格钉的是 **Rockchip RK3566 + AI 加速器**，内存 **1 GB RAM / 32 GB 存储**（**官方**：[新闻稿套件](https://pollen-robotics.com/microduck/press-kit/)、[商店页](https://store.pollen-robotics.com/products/microduck)）。规格没有写板厂型号。

板上软件把目标写死成 **Radxa Zero 3**（RK3566，Armbian，Debian Trixie 用户态）。设备树 `compatible = "radxa,zero-3w"`，对应市售 **Radxa ZERO 3W**，不是定制载板（**源码还原**：运行时仓库、`[updater-design.md](https://github.com/pollen-robotics/microduck/blob/main/docs/design/updater-design.md)`）。

Microduck 这套 SKU（1 GB + 32 GB eMMC）正好是 Zero 3W 的一档现成配置。

OpenMicroDuck 的立场不同：主控只要 **RK3566 同级**，能跑 50 Hz ONNX Runtime 控制环，并接上 40-pin HAT / CSI / UART。见 `[architecture.md](architecture.md)` §2.1。

---

## 3. RK3566 基本参数

RK3566 是瑞芯微 2020–2021 年的入门级 AIoT SoC。下表以芯片手册为准；板上实际主频、内存容量由模组决定。

RK3566 内部框图（Radxa 文档转载）

*图：RK3566 功能框图。来源：[Radxa ZERO 3 文档](https://docs.radxa.com/zero/zero3)。*

| 项目 | RK3566（芯片手册） | Radxa ZERO 3W 上的取值 |
| --- | --- | --- |
| CPU | 四核 Cortex-A55，每核 32 KB I + 32 KB D L1，共享 512 KB L3 | 最高 **1.6 GHz**（芯片本身常见标称 1.8 GHz）  |
| GPU | Mali-G52 1-Core-2EE；OpenGL ES 3.2 / Vulkan 1.1 / OpenCL 2.0 | 同左 |
| NPU | 单核，手册写 **最高 0.8 TOPS**；INT8 / INT16 卷积；RKNN 工具链 | 硅片有；Armbian 默认把节点关掉，见 §5 |
| 内存控制器  | 32-bit DDR3 / DDR4 / LPDDR3 / LPDDR4 / LPDDR4X，板上最多约 8 GB | **1 / 2 / 4 / 8 GB LPDDR4**（出厂焊死） |
| 视频 | 解码 4K@60 H.264/H.265/VP9；编码 1080p H.264/H.265 | Micro HDMI 只出到 **1080p60** |
| 相机 | 4-lane MIPI CSI + ISP（约 8M） | 22-pin CSI，官方配件走 IMX219 |
| 其它 I/O | USB 3.0、GbE MAC、PCIe 2.1 ×1、多路 UART / I²C / I²S / PWM | 引出见 §4 |

手册依据：[RK3566 Datasheet V1.1](https://rockchip.fr/RK3566%20datasheet%20V1.1.pdf)（芯片厂）。官方运行时文档同样写 NPU 为 **0.8 TOPS、单核 INT8**（`[npu-bringup.md](https://github.com/pollen-robotics/microduck/blob/main/docs/project/npu-bringup.md)`）。产品页只写「AI accelerator」，不写 TOPS。

对这只鸭子真正要紧的能力：

1. **四核 A55 + ≥1 GB RAM**：50 Hz 读 15 个舵机 + IMU、组 61 维观测、ONNX 推理、安全钳位，全在 CPU 上。
2. **MIPI CSI + ISP + MPP 编码器**：`mediad` 走摄像头和 H.264 推流。
3. **NPU**：板载视觉等 AI 功能的加速器；不进 50 Hz 平衡环。
4. **40-pin + UART + I²S**：HAT 上的半双工舵机、codec、ToF。

---

## 4. Radxa ZERO 3W

超小 SBC，刻意做成树莓派 Zero 外形：65×30 mm，40-pin，双 USB-C，板载 Wi-Fi 6。参数来自 [Radxa 产品页](https://www.radxa.com/products/zeros/zero3w/) 与 [产品 Brief](https://dl.radxa.com/zero3/docs/hw/3w/radxa_zero_3w_product_brief.pdf)（**官方**）。

Radxa ZERO 3W 正反面接口

*图：正反面标注。来源：[Radxa ZERO 3 文档](https://docs.radxa.com/zero/zero3)。*

ZERO 3W 系统框图

*图：RK3566 到板级外设。来源：同上；原理图标注为 Zero 3W V1.11。*

| 项目 | 规格 |
| ---- | --- |
| 尺寸 | **65 mm × 30 mm**（与 Pi Zero 同外形、同安装孔） |
| SoC  | RK3566，四核 A55 @ 最高 1.6 GHz |
| 内存 | 1 / 2 / 4 / 8 GB LPDDR4 |
| 存储 | 可选板载 eMMC 8–64 GB + microSD |
| 无线 | Wi-Fi 6 + BT 5.4 BLE；板载天线或外置 U.FL，软件切换 |
| USB  | USB 2.0 Type-C **OTG**（供电 + 刷机）+ USB 3.0 Type-C Host |
| 显示 | Micro HDMI，1080p60 |
| 相机 | 22-pin、0.5 mm 间距、4-lane MIPI CSI |
| 扩展 | 40-pin，GPIO 3.3 V；UART / SPI / I²C / I²S / PWM |
| 供电 | 5 V / 2 A，走 OTG 口 |
| 电源管理 | RK817（PMIC + 板载 codec） |

和鸭子相关的接口：

- **UART2**（40-pin 引出）→ HAT 半双工 → 舵机总线 + `imu_to_dxl`。Armbian 默认在 UART2 开 `serial-getty`，不 mask 会占死总线（`[architecture.md](architecture.md)` §2.2）。
- **I²C3 M0**（40-pin 的 3 / 5）→ HAT 上 codec、ToF。原厂同一控制器的 M1 给了 USB-C PD；官方 overlay 改到 M0 后失去 PD 协商，5 V 充电仍可用。
- **MIPI CSI** → IMX219 一类模组，`mediad` 用。
- **I²S** → HAT 上 TLV320AIC3104。
- **Wi-Fi / BT** → `configd` / `btd`，不经过 HAT。

同系列还有 **ZERO 3E**：同一颗 SoC、同一尺寸，用千兆网口换掉无线。鸭子需要板载 Wi-Fi / BT，3E 除非外挂无线，否则不合适。

---

## 5. NPU 有没有真的在用

只交叉 **Pollen 运行时仓** 与 **Hugging Face 官方资源**。结论先说：

**走路不用 NPU；NPU 是给视觉检测预留的，而且这条路径还没接到量产行为环。**

产品规格里的「AI accelerator」与 50 Hz 策略环不是同一件事。

### 5.1 运动策略：ONNX，CPU

三处对得上，都不是 RKNN：

| 来源 | 说了什么 |
| --- | --- |
| `[robotd-design.md](https://github.com/pollen-robotics/microduck/blob/main/docs/design/robotd-design.md)` | 策略文件是 `.onnx`；加载时校验观测/动作维数以及 **ONNX Runtime 是否存在**。ORT 是板级依赖，不打进发布包；`policy::ensure_runtime` 先探测 dylib，避免 `ort` 直接 panic 打死控制线程。 |
| 运行时 `[Cargo.toml](https://github.com/pollen-robotics/microduck/blob/main/Cargo.toml)` | `[workspace.metadata.onnxruntime]`：`robotd` **dlopen** ORT（floor 1.23 / target 1.28.0）。`[workspace.metadata.policies]` 指向 Hub 仓 `pollen-robotics/microduck-policies`。 |
| Hugging Face `[pollen-robotics/microduck-policies](https://huggingface.co/pollen-robotics/microduck-policies)` | 官方 9 个权重全是 `.onnx`（走、站、起坐、左右踢、地面拾取、翻滚、轮滑等），**没有** `.rknn`。 |
| Hugging Face `[pollen-robotics/microduck-simulator](https://huggingface.co/spaces/pollen-robotics/microduck-simulator)` | 浏览器里用 **onnxruntime-web** 按 **50 Hz** 跑同一套策略，与板上频率一致。 |

`npu-bringup.md` 也写明：用 NPU 的理由是 **别拖垮** `robotd` **的 50 Hz 环** —— 这反过来确认控制环不在 NPU 上。

### 5.2 鸭子检测：专为 NPU 写的，尚未进行为

官方文档 `[docs/project/npu-bringup.md](https://github.com/pollen-robotics/microduck/blob/main/docs/project/npu-bringup.md)` 的标题就是 *The NPU, and the duck detector on it*：

> The RK3566 has a small INT8 NPU — 0.8 TOPS, one core.

同一仓库里能独立对上的部分：

| 证据 | 内容 |
| --- | --- |
| `[Cargo.toml](https://github.com/pollen-robotics/microduck/blob/main/Cargo.toml)` | workspace 成员含 `duck-detect`；`[workspace.metadata.rknpu] runtime = "v2.3.2"`，注释写 `duck-detect` **dlopen** `librknnrt.so` **跑鸭子检测**。 |
| `[docs/README.md](https://github.com/pollen-robotics/microduck/blob/main/docs/README.md)` | 把 `npu-bringup.md` 列成「RK3566 NPU 上的鸭子检测：跑什么、如何基准、**以及仍然缺失的帧路径**」。 |
| `[roadmap.md](https://github.com/pollen-robotics/microduck/blob/main/docs/project/roadmap.md)` | 当前 in flight 列表含 **the NPU duck detector**（与 `maploc` 并列，尚未标成 landed）。 |
| `[architecture.md](https://github.com/pollen-robotics/microduck/blob/main/docs/design/architecture.md)` | 原则是「感知靠传感器」：`mediad` 拥有相机、**跑推理**、发特征，不把帧送给 `robotd`。这是设计终点，不是「已经在 `mediad` 里跑 RKNN」的声明。 |

bring-up 自己把缺口写死了：

- `duck-bench` **不进发布包**，用 scp 拷到板上测；将来行为要用检测器时，上船的是 `mediad` **里的检测器，不是这个工具**。
- **Nothing on the robot can get a frame.** `mediad` 已有 raw NV12 tee，但没有 IPC 把帧交出去。

因此：NPU 运行时和检测 crate 已经在官方仓里，**摄像头 → 检测 → 行为** 这一截官方仍标为缺失 / in flight。Hugging Face 上目前也搜不到官方 `.rknn` 权重（策略仓只有 ONNX）。

### 5.3 默认关着，靠更新脚本打开

`npu-bringup.md`：Armbian 在每块 Radxa Zero 3 上把 `npu@fde40000` 设成 `status = "disabled"`。板子、内核、驱动都在，NPU 仍是关的。`hooks/preinstall` 跑 `setup-npu.sh` 写 overlay，**需要重启** 才绑定。

`[updater-design.md](https://github.com/pollen-robotics/microduck/blob/main/docs/design/updater-design.md)` 补了一句工程史：加入检测器的分支曾经把 `setup-npu.sh` 打进发布包 **却没调用**，板上会带着一个碰不到 NPU 的检测器；后来才改成 preinstall 钩子。这与「硬件有、默认不可用」一致。

### 5.4 bring-up 里的数字：只当作一次官方自测

下面这组数 **只出现在** `npu-bringup.md`，Hugging Face 与其它官方设计文档没有复述。文档写的是一块 Radxa Zero 3、`duck-bench` 按 2 Hz、30 帧、3 趟：

| 项 | 文档给出的数 | 如何读 |
| --- | --- | --- |
| 驱动 / 运行时 | 0.9.8 / 2.3.2 | 2.3.2 与 `Cargo.toml` 的 `rknpu.runtime` **对得上** |
| 延迟 p50 / p95 | 25.7 ms / 58.4 ms | 文档定义为 infer + decode，**不含 JPEG** |
| 进程 CPU / 帧 | 20.7 ms | 文档明确说 **这不是 NPU 的成本**：含 CPU 上 1280×720 → 320×320 的 letterbox；`rknn_run` 是否忙等尚未分开测 |
| SoC 温度 | 63 °C | 跑完时的读数 |
| detections | 表格此格为空 | 文档只说对照已人工标注的帧，**没有在表里给出检出数** |

同一份文档还写了参考模型：YOLO11n、320×320、单类、INT8 后约 3.9 MB、held-out mAP50 0.976。训练仓 `[pollen-robotics/duck_detector](https://github.com/pollen-robotics/duck_detector)` **对外 404**，Hub 上也没有对应数据集/权重可复核，所以这些训练指标 **目前只能当作 bring-up 的自述，不能当作已公开可复现结果**。

### 5.5 另一条小网络：麦克风，不是 NPU

`[robotd-design.md](https://github.com/pollen-robotics/microduck/blob/main/docs/design/robotd-design.md)` / `[CONTRIBUTING.md](https://github.com/pollen-robotics/microduck/blob/main/CONTRIBUTING.md)`：`pet-detect` 是约 20 KB 的 CNN，对板载麦克风的 40-band log-mel 做头部抓挠一类分类，跑在 **自己的 worker** 里。这是 CPU 音频，与 RKNN 无关。

---

## 6. 外形：足够小

### 6.1 Zero 一类整板

约 65×30 mm、带 40-pin（或至少有焊盘）。**不是**性能等同。

| 板 | SoC | CPU | RAM | NPU | MIPI CSI | 无线 | 备注 |
| --- | --- | --- | --- | --- | --- | --- | --- |
| **Radxa ZERO 3W** | RK3566 | 4× A55 @ 1.6 GHz | 1–8 GB | 0.8 TOPS | 有 | Wi-Fi 6 / BT 5.4 | 官方开发目标 |
| **Raspberry Pi Zero 2 W** | BCM2710A1（RP3A0 SiP） | 4× A53 @ 1 GHz | **512 MB** | 无 | 有 | Wi-Fi 4 / BT 4.2 | Open Duck Mini、早期 `microduck_runtime`、[Rhoban microban](https://github.com/Rhoban/microban) 都用过 |
| **Orange Pi Zero 2W** | Allwinner H618 | 4× A53 @ 1.5 GHz | 1–4 GB | 无 | **无**（CSI 位置改成 24-pin FPC） | Wi-Fi 5 / BT 5.0 | 40-pin 有；摄像头要另想办法 |
| **BPI-M4 Zero** | Allwinner H618 | 4× A53 @ 1.5 GHz | 2 / 4 GB | 无 | **无**（同样是 24-pin FPC） | Wi-Fi 4/5 / BT 5.0 | 与 Orange Pi Zero 2W 几乎同构，多一颗 eMMC |

要点：

- **Pi Zero 2W** 是历史基线，不是性能上限。512 MB、无 NPU、A53 @ 1 GHz，能跑早期运行时；同时扛 50 Hz ORT + `mediad` 推流会紧。无 NPU 则官方那套 RKNN 视觉检测走不通。优点是生态、CSI、HAT 资料最多。
- **H618 两块** 外形能装进同一套壳，但没有 CSI，也没有 RKNN。
- 同尺寸、同 SoC 的还有 **Geniatech XPI-3566-ZERO** 一类 RK3566 Zero 板，缺货时值得核 CSI 针脚和 40-pin 复用是否与 Radxa 接近。

### 6.2 CM4 兼容核心板

把主控塞进 **头里或身体里**，硬约束是体积和重量。如果HAT板要重新画，那么，不是必须复刻 Pi Zero 的 40-pin 外形。官方走 Zero 3W，是因为它已经足够小、现成带无线和 CSI。如果未来载板要适配ID设计或其他接口重画，载板形状可以跟核心板走，不必再迁就 40-pin 针脚。

两条都能用：

1. **整板 SBC**（Zero 一类）。
2. **CM4 兼容核心板 + 自制载板**：SoM 约 **55×40 mm**，双 100-pin 高密座；UART / I²C / I²S / CSI / 电源都引到载板上。市面上 CM4 外形的核心板很多，换 SoC 往往不用重画结构件，只改载板和设备树。

Raspberry Pi Compute Module 4 把 SoC、内存、eMMC、无线收成 **55×40 mm** 模组，用两排 100-pin 座接到载板。这个封装已经被多家做成 **针脚大体兼容** 的核心板，SoC 从 BCM2711 换到 RK3566 / RK3568 / 其它 Arm 都有。对我们来说，载板 = 原来的 HAT：半双工舵机、codec、ToF、电池配电，再加上 CM4 座和 CSI。

「兼容」指机械尺寸和高速座能对上常见 CM4 IO；CSI / DSI 路数、无线、eMMC 启动各家仍有差异，自制载板按选定模组画，不要假设插上 Pi 的 CM4 IO 就一切可用。

| 核心板 | SoC | 相对 Zero 3W | 备注 |
| --- | --- | --- | --- |
| **Raspberry Pi CM4** | BCM2711，4× A72 | CPU 更强；**无 NPU** | 原版封装；无线 / eMMC 可选 |
| **Radxa CM3** | **RK3566**，4× A55 | 与官方同族 SoC，有 NPU  | 55×40 mm；厂商称可配多种 CM4 载板 |
| **Radxa CM3I** 等 | RK3568(J) | 同族、接口更多 | 模组略大（约 70×40 mm），工业温区选项 |
| **Orange Pi CM4** / **Pine64 SOQuartz** 等 | 多为 RK3566 | 同族 NPU | 缺货时的平替；针脚与无线要逐款核 |
| **Banana Pi BPI-CM4** 等 | 其它 SoC（如 A311D） | 外形同 CM4，软件栈不同 | 有独立 NPU 的型号才适合做视觉 |

优先看 **RK3566 的 CM4 模组**（Radxa CM3 一类）：体积够小、算力对齐官方、NPU 还在。Pi CM4 本身能跑 ORT 走路，但没有 RKNN，视觉要另找加速路径。

---

## 7. SoC 性能接近的

走路要的是：能跑 Linux、核数/单核不低于四核 A55 这一档、≥1 GB RAM、能稳定 50 Hz 推理。板载视觉等 AI 功能要有可用的加速器（官方栈是 RKNN；其它 SoC 可以是别的运行时）。

| SoC | CPU | AI / NPU | 和 RK3566 的关系 | 谁在卖板 |
| --- | --- | --- | --- | --- |
| **RK3566** | 4× A55，常见 1.6–1.8 GHz | 独立 NPU **0.8 TOPS**（RKNN） | 基准 | Radxa Zero 3、不少工业模组 / CM4 外形板 |
| **RK3568** | 4× A55，常见最高 2.0 GHz | 手册同族，多为 0.8 TOPS | 同一 CPU/GPU/NPU 家族；多 PCIe 3.0、双 GbE、SATA、编码到 4K | 工业板、部分 NAS / 面板；**几乎没有 Zero 外形**  |
| **进迭时空 K1**（SpacemiT Key Stone K1） | **8×** 自研 X60，**RISC-V** 64GCVB / RVA22，常见 1.6–2.0 GHz | **2.0 TOPS** INT8（CPU 指令扩展融合，不是 RKNN 那颗独立 NPU） | 开源指令集；核数和 AI 算力都明显高于基准；官方 `.rknn` 不能直接用，ORT 等要编 riscv64 | Banana Pi BPI-F3、Milk-V Jupiter 等 |
| **BCM2710A1** | 4× A53 @ 1 GHz | 无 | 明显更弱，无 NPU | 只出现在 Pi 3 / Zero 2W / 对应 CM |
| **BCM2711** | 4× A72 @ 1.5–1.8 GHz | 无 | CPU 单核强于 A55；无 RKNN | Pi 4 / CM4 / Pi 400 |
| **BCM2712** | 4× A76 @ 2.4 GHz | 无（Pi 5 走 CPU / GPU） | 明显更强，板更大、更贵、更耗电 | Pi 5 / CM5 |

树莓派这几颗 Broadcom 芯片 **基本只出现在树莓派自己的板和 Compute Module 上**。第三方买不到裸片去做「Pi 芯片 + 国产载板」；能买的是 Pi 整板或 CM + 载板。RK3566 / RK3568 则是开放供货的 SoC，国内模组厂很多。

RK3568 对软件几乎可当作「带更多接口的 RK3566」：同一套 RKNN、同一套 MPP。整板开发板通常是 100 mm 级，塞不进头/身体；**CM4 外形的 RK3568 模组**（如 Radxa CM3I）则仍可能装进去，见 §6.2。桌面上先跑通再缩回模组，也说得通。

**K1** 走的是开源 **RISC-V**，不是 Arm。Bianbu Robot 是基于K1的智能机器人软硬件协同解决方案。手册把 8 核拆成两个 cluster：cluster 0 四核带 2.0 TOPS AI 扩展，cluster 1 四核是普通核；AI 算力做在 CPU 自定义指令上（厂商称 Daoyi），宣称支持 TensorFlow Lite / ONNX Runtime，不是像RK3566 那种独立 NPU 和 RKNN 工具链。相对 0.8 TOPS，2.0 TOPS 强得多，视觉头更宽裕；走路策略本身是 ONNX，理论上也可以在 riscv64 的 ORT 上跑，但官方 `aarch64` 发布包、设备树 overlay、MPP/GStreamer 插件都要重做。功耗方面，板厂给出大约 **TDP 3–5 W**、对外介绍典型约 3.5 W，比 Zero 形态的 RK3566 模组更可能偏高，电池和散热要重新评估，不默认当「塞进同一只 800 g 鸭子就完事」。

比 RK3566 更强的 RK3588（6 TOPS 级）能跑，但功耗、价格、散热都超过这只 800 g 机器的需求，不作为默认档。

---

## 8. 主要来源

- RK3566 手册：[https://rockchip.fr/RK3566%20datasheet%20V1.1.pdf](https://rockchip.fr/RK3566%20datasheet%20V1.1.pdf)
- Radxa ZERO 3：[https://docs.radxa.com/zero/zero3](https://docs.radxa.com/zero/zero3) · [产品 Brief](https://dl.radxa.com/zero3/docs/hw/3w/radxa_zero_3w_product_brief.pdf)
- Microduck 规格：[新闻稿套件](https://pollen-robotics.com/microduck/press-kit/) · [商店页](https://store.pollen-robotics.com/products/microduck)
- 运行时架构 / 控制环：[architecture.md](https://github.com/pollen-robotics/microduck/blob/main/docs/design/architecture.md) · [robotd-design.md](https://github.com/pollen-robotics/microduck/blob/main/docs/design/robotd-design.md)
- NPU bring-up：[npu-bringup.md](https://github.com/pollen-robotics/microduck/blob/main/docs/project/npu-bringup.md) · [roadmap.md](https://github.com/pollen-robotics/microduck/blob/main/docs/project/roadmap.md) · [Cargo.toml](https://github.com/pollen-robotics/microduck/blob/main/Cargo.toml)
- Hugging Face 策略：[pollen-robotics/microduck-policies](https://huggingface.co/pollen-robotics/microduck-policies)（9× `.onnx`）
- Hugging Face 模拟器：[pollen-robotics/microduck-simulator](https://huggingface.co/spaces/pollen-robotics/microduck-simulator)（onnxruntime-web @ 50 Hz）
- 更新器硬件目标：[updater-design.md](https://github.com/pollen-robotics/microduck/blob/main/docs/design/updater-design.md)
- 板级架构还原：`[architecture.md](architecture.md)` §2.2
- Pi Zero 2W Brief：[Raspberry Pi 产品简介 PDF](https://pip-assets.raspberrypi.com/categories/584-raspberry-pi-zero-2-w/documents/RP-008359-DS-1-raspberry-pi-zero-2-w-product-brief.pdf)
- Orange Pi Zero 2W：[Wiki](http://www.orangepi.org/orangepiwiki/index.php/Orange_Pi_Zero_2W)
- BPI-M4 Zero：[Banana Pi 文档](https://docs.banana-pi.org/en/BPI-M4_Zero/BananaPi_BPI-M4_Zero)
- Raspberry Pi CM4：[Compute Module 介绍](https://www.raspberrypi.com/documentation/computers/compute-module.html)
- Radxa CM3（CM4 兼容、RK3566）：[产品介绍](https://docs.radxa.com/en/som/cm/cm3/getting-started/introduction)
- 进迭时空 K1：[芯片手册](https://cdn-resource.spacemit.com/file/chip/K1/K1_datasheet_en.pdf) · [docs-chip](https://github.com/spacemit-com/docs-chip/blob/main/en/key_stone/k1/k1_docs/k1_ds.md) · [BPI-F3 / K1 简介](https://docs.banana-pi.org/zh/BPI-F3/SpacemiT_K1)

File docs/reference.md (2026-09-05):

# 参考项目

Microduck 相关资源散落在 GitHub 多个组织和 Hugging Face 三类资源（Space / Model / Dataset）里。

本文整理自社区相关的项目，统计数据可能会随时间变化不定期更新。

本仓库（[JoyandAI/OpenMicroDuck](https://github.com/JoyandAI/OpenMicroDuck)）受 Hugging Face / Pollen Robotics 的 Microduck 启发，走完全开源路线；与官方及下列社区项目无隶属关系。

难免有误不全之处，请多核实。

---

## 官方仓库（pollen-robotics）

| 仓库 | Star | 许可 | 简介 |
| --- | ---- | --- | --- |
| **[microduck](https://github.com/pollen-robotics/microduck)** | 7356 | Apache-2.0 | 板载软件：`robotd` 50Hz 控制环、`mediad` 摄像头/WebRTC、`padd` 手柄、更新器。设备路径、I²C 地址、寄存器写死在代码里 |
| **[microduck_rl](https://github.com/pollen-robotics/microduck_rl)** | 1758 | Apache-2.0 | RL 训练环境（mjlab / MuJoCo Warp），含 PPO、BAM 执行器模型、回差仿真与域随机化；**47 个 STL + 完整 MJCF**。需要 CUDA |
| **[elec_RPI_Robot_HAT](https://github.com/pollen-robotics/elec_RPI_Robot_HAT)** | 24 | Apache-2.0 | HAT 板完整 KiCad 9 工程：原理图、PCB、Gerber、BOM、贴片坐标、STEP；`production/` 可直接打样（4 层板） |
| **[lib_KiCAD](https://github.com/pollen-robotics/lib_KiCAD)** | 3 | — | Pollen 的 KiCad 符号 / 封装 / 3D 库。打开上面工程必须先装，否则一片未解析符号 |
| [rustypot](https://github.com/pollen-robotics/rustypot) | 57 | Apache-2.0 | Dynamixel 通信库；运行时靠它跟舵机说话，`xl330.rs` 里是完整寄存器表 |
| [microduck-gst-plugins](https://github.com/pollen-robotics/microduck-gst-plugins) | 14 | Apache-2.0 | 预编译 aarch64 GStreamer 插件：Rockchip MPP 硬件编码器 + gst-plugins-rs WebRTC，供板载 `mediad` 使用 |
| `duck_detector` | — | — | 不公开（404）。官方文档引用过的 NPU 检测模型训练仓，外部访问不到 |

### 官方站点与文档

| 名称 | 简介 |
| --- | --- |
| [产品页](https://pollen-robotics.com/microduck) | 规格、配色与发布说明 |
| [商店](https://store.pollen-robotics.com/products/microduck) | 官方预售，定价 $399 |
| [新闻稿套件](https://pollen-robotics.com/microduck/press-kit/) | 规格表、照片与下载素材 |
| [Meet Microduck](https://pollen-robotics.com/microduck/blog/introducing-microduck/) | Pollen 发布博文 |
| [文档索引](https://github.com/pollen-robotics/microduck/blob/main/docs/README.md) | 运行时仓库内全部文档入口 |
| [架构说明](https://github.com/pollen-robotics/microduck/blob/main/docs/design/architecture.md) | 守护进程、控制环、策略与更新器如何拼在一起 |
| [策略通道设计](https://github.com/pollen-robotics/microduck/blob/policy-hub-design/docs/design/policy-channel-design.md) | 社区策略如何上机：Hub 仓库布局、`manifest.json` 契约、`robotctl policy` 命令（仍在分支，未合入 main） |
| [路线图](https://github.com/pollen-robotics/microduck/blob/main/docs/project/roadmap.md) | 里程碑 M1–M9，含 Hub 模型通道（M8）与自主大脑（M9） |

---

## Hugging Face

### 模拟器与可视化

| 名称 | Likes | 简介 |
| --- | ----- | --- |
| **[pollen-robotics/microduck-simulator](https://huggingface.co/spaces/pollen-robotics/microduck-simulator)** | 418 | 官方网页沙盒：MuJoCo WASM + onnxruntime-web，50Hz 跑真实策略，支持手柄与轮滑变体 |
| [mishig/microduck-anatomy](https://huggingface.co/spaces/mishig/microduck-anatomy) | 10 | 交互式解剖可视化，可分阶段聚焦零件与爆炸装配 |
| [multimodalart/microduck-ar](https://huggingface.co/spaces/multimodalart/microduck-ar) | 1 | 官方沙盒的 WebXR 适配：真实地面放置 + 地面拾取 |
| [ysharma/gr-workflow-microduck-lab](https://huggingface.co/spaces/ysharma/gr-workflow-microduck-lab) | 1 | 把一段自然语言例程编排成技能序列再回放 |
| [osolmaz/microquack](https://huggingface.co/spaces/osolmaz/microquack) | 1 | 程序化机器人语音，Rust 核心经 WASM 在浏览器里实时合成 |

### 策略模型

| 名称 | Likes | 简介 |
| --- | ----- | --- |
| **[pollen-robotics/microduck-policies](https://huggingface.co/pollen-robotics/microduck-policies)** | 8 | 官方 9 个 ONNX（站立、行走、起坐、踢球、地面拾取、翻滚、轮滑等），不必克隆运行时即可拉取 |
| [RemiFabre/microduck-flamingo-cycle](https://huggingface.co/RemiFabre/microduck-flamingo-cycle) | 23 | 单脚站立并可左右切换 |
| [joanfox/microduck-happy-hop](https://huggingface.co/joanfox/microduck-happy-hop) | 3 | 跳跃 |
| [q2p/microduck-beak-throw](https://huggingface.co/q2p/microduck-beak-throw) | 2 | 用喙把物体抛出 |
| [fffiloni/microduck-polite-bow-b1d864](https://huggingface.co/fffiloni/microduck-polite-bow-b1d864) | 2 | 鞠躬 |
| [fffiloni/microduck-moonwalk-backward-55e6af](https://huggingface.co/fffiloni/microduck-moonwalk-backward-55e6af) | 1 | 向后太空步 |
| [RemiFabre/microduck-rough-walk-g](https://huggingface.co/RemiFabre/microduck-rough-walk-g) | 1 | 崎岖地面行走（g） |
| [HannesVonEssen/microduck-running](https://huggingface.co/HannesVonEssen/microduck-running) | 1 | 奔跑 |
| [Nupr-Haokun/microduck-step-up-head-brake](https://huggingface.co/Nupr-Haokun/microduck-step-up-head-brake) | 1 | 用头当临时刹车跨 25mm 台阶，再恢复直立 |

上游提供 `uv run publish`，可以把自训策略发到 Hub。契约约定：每个 Hub 仓库一份 `.onnx` + `manifest.json`（观测/动作维数、模型 API 版本、机型兼容性）。更多社区步态见 [Hub 搜索](https://huggingface.co/models?search=microduck)。

### 数据集

| 名称 | Likes | 简介 |
| --- | ----- | --- |
| [craigm26/microduck-stairs-challenge](https://huggingface.co/datasets/craigm26/microduck-stairs-challenge) | 1 | 爬楼梯打分基准，物理模型按哈希钉死（仅仿真） |

> 数据集集中出现在 2026 年 9 月初，是社区从「玩」转向「训」的信号。

---

## 社区项目

### 工具、Agent 与应用

| 仓库 | Star | 简介 |
| --- | ---- | --- |
| [rokbenko/quackd](https://github.com/rokbenko/quackd) | 160  | 自然语言目标规划守护进程：用现有技能编排任务。自带模拟器、`.duck` 任务文件、安全规则、MCP，已上 PyPI；0.4 起也驱动其他小机器人 |
| [jonathanhawkins/microduck-lab](https://github.com/jonathanhawkins/microduck-lab) | 78 | 在普通 Mac 上训 RL，不需要 CUDA；同一套 MJCF 与 61/14 契约，带浏览器实时查看 |
| [joeynyc/awesome-microduck](https://github.com/joeynyc/awesome-microduck) | 75 | 英文策展列表：软件、模拟器、策略、Agent 工具与媒体报道 |
| [craigm26/duckkit](https://github.com/craigm26/duckkit) | 6 | 纯 Swift 包：真实 ONNX + 61 维观测 @ 50Hz，含运动学、协议类型和 Linux 测试 |
| [aj-dev-smith/microduck-mcp](https://github.com/aj-dev-smith/microduck-mcp) | 2 | MCP 驱动 CPU MuJoCo 仿真鸭，工具输出含渲染画面，带 Agent 调试页（仅仿真） |
| [joeynyc/microduck-mcp](https://github.com/joeynyc/microduck-mcp) | 1 | 按真机 `robotd` 架构做的 MCP：mock / MuJoCo / Unix socket / SSH 同一套工具，带安全层。硬件传输尚未在真机验证 |
| [jvpflum/microduck-lab](https://github.com/jvpflum/microduck-lab) | 1 | 面向 NVIDIA DGX Spark 的可复现训练工作区，把官方运行时、模拟器和 `microduck_rl` 钉成子模块 |
| [carpentry-liu/rl-physics-overlay](https://github.com/carpentry-liu/rl-physics-overlay) | 1 | 浏览器模拟器的无依赖遥测叠加层：关节力、力矩、接触与学习信号（中英） |
| [kgediya/specs-microduck](https://github.com/kgediya/specs-microduck) | 1 | 用 Snap Spectacles 手势遥操作仿真鸭，镜内显示遥测 |
| [ngxson/wicroduck](https://github.com/ngxson/wicroduck) | 1 | 整条回路塞进 URL：浏览器 WASM 步进真实 MJCF，无 Python、无后端。仿真已通，浏览器内训练仍是目标 |

站点（非 GitHub 仓）：[MicroduckHub](https://microduckhub.com)（社区策略浏览器）、[uDuck Registry](https://uduck-registry.pages.dev)（策略描述符目录）、[OpenCastor 集成](https://docs.opencastor.com/robots/microduck/)、[Strands Robots provider](https://strands-labs.github.io/robots/policies/microduck/)、[microquack 网页](https://osolmaz.github.io/microquack/)。

### 训练与仿真

| 仓库 | Star | 简介 |
| --- | ---- | --- |
| [Vottivott/microduck-playground](https://github.com/Vottivott/microduck-playground) | 30 | `microduck_rl` 的独立续作：可复现实验、策略演示、可打印附加件，停留在上游某次提交上 |
| [AlexBodner/microduck-tracking](https://github.com/AlexBodner/microduck-tracking) | 13 | 基于 roboflow/trackers 的多目标跟踪：在干扰物中锁定并取回一只球 |
| [metahubaifeel/microduck-rl-on-thor](https://github.com/metahubaifeel/microduck-rl-on-thor) | 12 | 让官方训练栈跑在 aarch64 CUDA（Thor / DGX Spark / Jetson），坑已在真机核对（中英） |
| [kabilankb/isaaclab-microduck](https://github.com/kabilankb/isaaclab-microduck) | 8 | Isaac Lab 3.0 / Newton MJWarp：运动、奔跑、踢球、双机对打，并与 mjlab 基线做 A/B |
| [Macmachi/microduck-rl-genesis](https://github.com/Macmachi/microduck-rl-genesis) | 3 | Genesis 移植行走任务，面向 AMD/ROCm；执行器模型相对上游 bit-exact |
| [osrbot/microduck-ros2-isaac](https://github.com/osrbot/microduck-ros2-isaac) | 2 | ROS 2 Jazzy + Isaac Sim 教程：RViz 关节控制，USD 里跑官方行走策略 |
| [Lulzx/microduck-backflip](https://github.com/Lulzx/microduck-backflip) | 1 | 可复现后空翻任务，含评估集、实验日志和明确安全门（仅仿真） |
| [selinayfilizp/microduck-courier](https://github.com/selinayfilizp/microduck-courier) | 2 | 公寓场景里的拾-运-放，含策略、rollout 与遥测（仅仿真） |
| [yangyihai/Microduck_RL_Ball_Follow](https://github.com/yangyihai/Microduck_RL_Ball_Follow) | 1 | MuJoCo Warp 追球任务 + 指令块契约层 + 拖球演示（仅仿真） |
| [Liyucheng1997/318_lab-microduck-simulator](https://github.com/Liyucheng1997/318_lab-microduck-simulator) | 1 | 官方沙盒分叉，带自训垂直跳策略；[在线演示](https://duck.liyucheng.me) |

### 复刻与硬件

| 仓库 | Star | 简介 |
| --- | ---- | --- |
| **[JoyandAI/OpenMicroDuck](https://github.com/JoyandAI/OpenMicroDuck)**（本仓库） | 32 | 完全开源复现：国产供应链、图纸 / PCB / BOM / 软件栈规划全公开 |
| [fanhao375/microduck-replica](https://github.com/fanhao375/microduck-replica) | 471  | 从官方 MJCF/STL/Rust 反推装配图、CAD 装配体、紧固件清单与电控方案（Radxa Zero 3W、TTL 总线、两块自制板）；未对真机核验 |
| [IronSpiderMan/MicroDuckModels](https://github.com/IronSpiderMan/MicroDuckModels) | 34 | Three.js + R3F 浏览器模拟器，MuJoCo WASM + 本地 ONNX，跑齐官方 9 个策略（中英 README） |
| [ScrapMeta/microduck-diy](https://github.com/ScrapMeta/microduck-diy) | 18 | 「一个月手搓」日志：公开仿真网格 + 打印件，分阶段文件和零件清单（中文） |
| [SaberOnGo/open-microduck](https://github.com/SaberOnGo/open-microduck) | 7 | 中英双语硬件/软件栈文档，明确写了官方硬件未开源；目前以文档为主，无 PCB 文件 |
| [boris721/microduck-3d](https://github.com/boris721/microduck-3d) | 6 | 从官方模拟器提取的 STL + MJCF |
| [lingzolabs/microduck-hardware-replica](https://github.com/lingzolabs/microduck-hardware-replica) | 1 | FreeCAD 多件装配、可打印网格、规划阶段 BOM；中文，声明无隶属、未核验 |
| [Shiyao-Huang/ChinaMicroDuck](https://github.com/Shiyao-Huang/ChinaMicroDuck) | 1 | 复刻参考库：四条成本化制造路线对照、官方资产许可审计、环境核验报告、官方文档中译 |
| [Rhoban/microban](https://github.com/Rhoban/microban) | 283  | **不是 Microduck**，但用同一块 HAT。19×XL330 + Pi Zero 2W，完整公开 BOM 与装配指南（约 $567） |

### 谱系与历史

Microduck 从 Antoine Pirrone 的开源硬件 [Open Duck Mini](https://github.com/apirrone/Open_Duck_Mini) 演进而来，两边仍共享 Discord、执行器模型和 sim-to-real 经验。

| 仓库 | Star | 简介 |
| --- | ---- | --- |
| [apirrone/Open_Duck_Mini](https://github.com/apirrone/Open_Duck_Mini) | 3965 | 开源硬件前身：BOM、CAD，以及最初的 mjlab 训练工作 |
| [apirrone/Open_Duck_Mini_Runtime](https://github.com/apirrone/Open_Duck_Mini_Runtime) | 172  | Open Duck Mini 的 Raspberry Pi 运行时 |
| [TommyZihao/microduck_runtime](https://github.com/TommyZihao/microduck_runtime) | 3 | 原型机运行时公开镜像（原仓 `apirrone/microduck_runtime` 已私有）。原型机 IMU 是 BNO055 走 I²C，不是现在的 `imu_to_dxl`；已被 `pollen-robotics/microduck` 取代 |
| [apirrone/microduck_maploc_rs](https://github.com/apirrone/microduck_maploc_rs) | 6 | 原型机用的 ToF 子图 SLAM / 重定位 / A（Rust）。目标运行时未公开，crate 本身开源 |

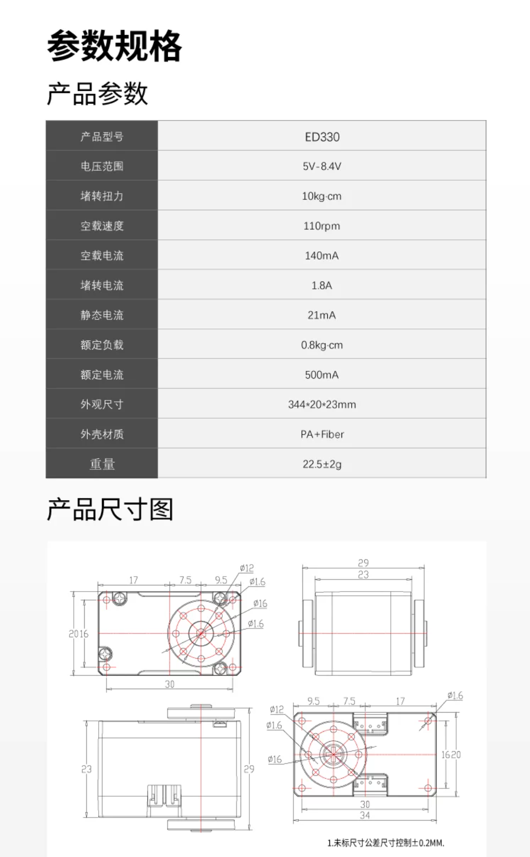
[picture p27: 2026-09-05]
hardware_spec/servo/ED330-servo-spec.png

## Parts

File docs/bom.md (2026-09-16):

# OpenMicroDuck BOM

> 适用于 OpenMicroDuck 整机装配。结构件与 **HD-1910 / HL-2909** 舵机版本兼容。
> 采购参考价与购买链接见根目录 [README.md](../README.md#bom)，本文不重复。

由于整机集成度比较高，如果完全等所有零配件都 ready，再塞进鸭子离线跑，可能要等待比较长的时间。这里分两个阶段：

- **桌面调试版**：主控和舵机驱动板外置，可由电源适配器供电，主控可接显示屏，舵机可由驱动板直接连 PC，方便调试。
- **整机集成版**：Zero HAT 板和 IMU 转接板完成后，把已调试好的模型和软件部署进机体内，形成完整整机。

结构件打印与装配见 [structure.md](structure.md)。

---

## 共用件

两个版本都要用到的器件。

### 通用电子器件

| 器件 | 型号 | 规格 | 数量 | 备注 |
|---|---|---|---|---|
| 舵机 | 飞特 HD-1910-C001 | 恒力空心杯舵机，4~8.4V，堵转扭矩 12kg·cm | 15 | 换型号必须重训策略 |
| 主控 | Radxa ZERO 3W | RK3566，2GB RAM，带 WiFi，无 eMMC，带排针版 | 1 | 系统装在 MicroSD 上 |
| SD卡 | MicroSD / TF 卡 | 64GB，A2 | 1 | 无 eMMC 时必需 |
| 摄像头模组 | IMX219 | MIPI FPC 排线，500 万像素 | 1 | CSI 接口 |
| 麦克风 | — | — | — | 料号未定 |
| 扬声器 | — | — | — | 料号未定 |

### 紧固五金件

| 器件 | 规格 | 数量 | 备注 |
| --- | --- | ---- | --- |
| M2自攻螺丝 | M2×5 十字平尾自攻螺丝，黑色 | 56 | 锁大部分 |
| M2自攻螺丝 | M2×6 十字平尾自攻螺丝，黑色 | 14 | 锁小部分舵盘和脚 |
| M2自攻螺丝 | M2×8 十字平尾自攻螺丝，黑色 | 46 | 锁舵机 |
| M2.5自攻螺丝 | M2.5×8 十字平尾自攻螺丝，黑色 | 11 | 头部内结构固定 |
| M2扁头自攻螺丝 | - | 4 | 舵机自带，不需要另外购买 |
| 6700K轴承 | 10 × 15 × 3 mm | 3 | — |
| ET2216轴承 | 16 × 22 × 4 mm | 1 | — |

### 结构件

3D打印，推荐PLA材料，脚垫可以尝试 TPU-95。

| 部件 | 数量 | 备注 |
| --- | ---- | ---- |
| ankle_left | 1 | - |
| ankle_right | 1 | - |
| banana_pcb_locker | 1 | - |
| bottom_head_shell | 1 | - |
| face_part | 1 | - |
| foot_left | 1 | - |
| foot_right | 1 | - |
| hip_l | 1 | - |
| hip_l1 | 1 | - |
| jaw | 1 | - |
| jaw_soft | 1 | - |
| left_shell | 1 | - |
| leg | 1 | - |
| leg2 | 1 | - |
| motor_support | 1 | - |
| neck | 1 | - |
| neck1 | 1 | - |
| neck_pitch | 1 | - |
| noenoeil | 1 | - |
| power_support | 1 | - |
| right_shell | 1 | - |
| soft_mouth_top | 1 | - |
| sole_left | 1 | - |
| sole_right | 1 | - |
| top_head_shell | 1 | - |
| trunk_base | 1 | - |
| upper_leg_left | 1 | - |
| upper_leg_right | 1 | - |
| upper_leg_rigidity_plate  | 1 | - |
| upper_leg_rigidity_plate1 | 1 | - |
| yaw2roll | 1 | - |
| yaw2roll1 | 1 | - |
| yaw_roll_motion | 1 | - |

---

## 不同阶段有差异器件

桌面调试把主控和舵机驱动板留在体外，用现成模组和电源适配器先把控制和策略跑通；整机集成要把电池、所有连接线都放到机器人内部。下面只列**不同**的器件。

### 桌面调试版

| 器件 | 型号 | 规格 | 数量 | 原因 |
|---|---|---|---|---|
| IMU 模组 | LSM6DSV16X 模块 | 支持 I2C 和 SPI | 1 | `IMU_to_servo` 自制板尚未就绪。成品模组可直接挂到主控的 I2C/SPI，先读取陀螺仪和加速度数据用于闭环控制。 |
| 舵机转接线 | PH2.0 转 5264 3P | 先用 1 根 PH2.0 3P 接驳 1 根 5264 3P | 1 | 外置飞特 URT2 口是 5264/AMP-3，HD-1910 是 AMP2.0-3P，中间必须转接。整机HAT上直接预留PH2.0口，不再需要这根线。 |
| 电线 | 特软硅胶线、铁氟龙线 | 约 30 cm | 若干 | 主控、驱动板、舵机都在体外，距离比机内线束长，需要加长线。 |

桌面调试阶段的总线驱动和供电见下文「研发辅助材料」（URT2、舵机适配器、主控 PD 适配器）。它们不是每台整机量产件，但是桌面调试版要把舵机和主控跑起来所必需的。

### 整机集成版

| 器件 | 型号 | 规格 | 数量 | 原因 |
|---|---|---|---|---|
| Zero Robot HAT 转接板 | — | 插在 ZERO 3W 的 40-pin 上 | 1 | 体内需要半双工舵机换向、电池配电、以及 I²C / I²S 外设。URT2 体积和接口都不适合塞进鸭子，HAT 回片后替换外置驱动板。 |
| IMU_to_servo 转接板 | 板载 LSM6DSV16X | 挂在舵机总线上，规划从机 ID 200 | 1 | 整机要对齐官方 50 Hz 契约：IMU 与 15 颗舵机同一趟 `sync_read`，不能再走主控上的裸 I2C 模组。 |
| 电池 | 7.4V 3400mAh 2S 锂电池组 | 18650 2 串，放电倍率 2C，XH2.54 2P 公头 | 1 | 离线整机不再用墙供；经 HAT 给舵机轨和主控配电。桌面调试用适配器，不必等电池组。 |

---

## 研发辅助材料

研发调试用，**不是**每台机器人必须的 BOM。主要服务桌面调试：外置供电、改舵机 ID / 中位校准、给主控接显示器和烧录SD卡。

| 器件 | 型号 | 规格 | 数量 | 备注 |
|---|---|---|---|---|
| 舵机驱动板 | 飞特 URT2 串口总线舵机驱动板 | Type-C 接口 | 1 | 桌面调试的总线入口；可直接连 PC。整机集成后由 HAT 取代。 |
| 舵机电源适配器 | 7.5V 舵机电源适配器 | 7.5V 3A，DC 5.5×2.1 插头，3C 认证 | 1 | 给外置 URT2 / 舵机供电。整机改用电池组供电。 |
| 主控电源适配器 | PD 直流电源适配器 | Type-C PD，确认支持 5V 3A 或 5V 2A | 1 | 主控外置时单独供电。 |
| 数据线 | USB Type-C→Type-A 或双头 Type-C | 0.5m~1.5m | 1 | 刷机、串口、URT2 连 PC。 |
| MicroHDMI 线 | MicroHDMI→HDMI | 约 1.5m | 1 | 桌面调试给主控接显示器；整机不需要。 |
| 读卡器 | MicroSD 卡读卡器 | USB 2.0 即可 | 1 | 笔记本已有读卡器则不必另买。 |

---

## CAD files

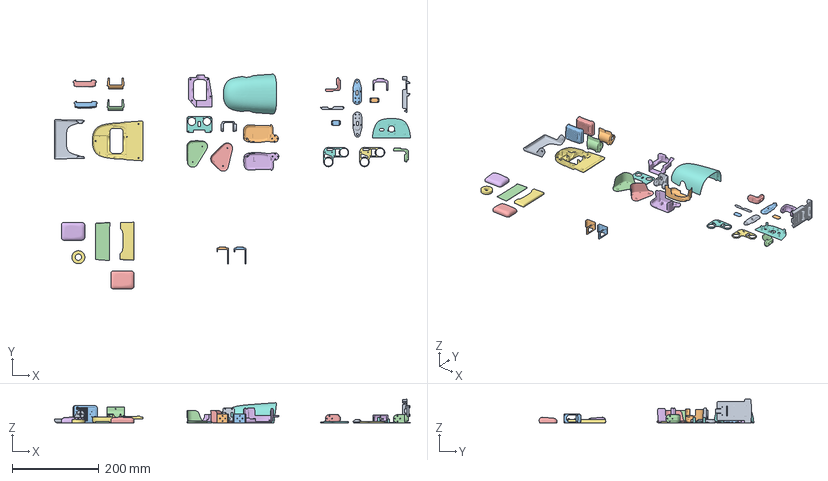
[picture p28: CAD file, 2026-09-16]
cad/openmicroduck.3mf
819.5 x 494.3 x 54.5 mm
leg1
ankle.stl_2
leg
ankle.stl_1
foot_right
neck_pitch
bottom_head_shell
face_part
jaw
right_shell
foot_left
hip_l
hip_l1
motor_support
upper_leg_rigidity_plate1
upper_leg_rigidity_plate
banana_pcb_locker
neck
neck1
soft_mouth_top
sole_right
sole_left
noenoeil
top_head_shell.stl
yaw_roll_motion
yaw2roll1
yaw2roll
upper leg.stl_1
upper leg.stl_2
left s.stl
js.stl
trunk_base.stl
asd.stl_1

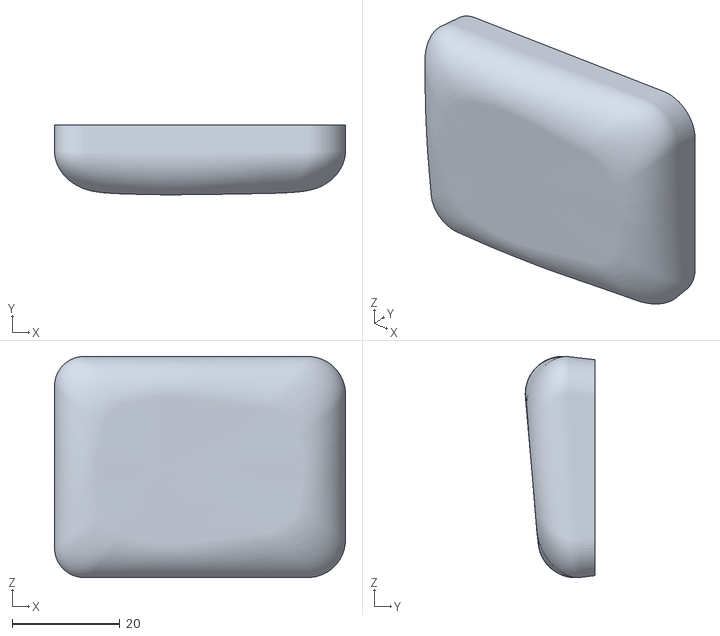
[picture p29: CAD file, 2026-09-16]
cad/parts/sole_left.stl
54.0 x 12.9 x 41.1

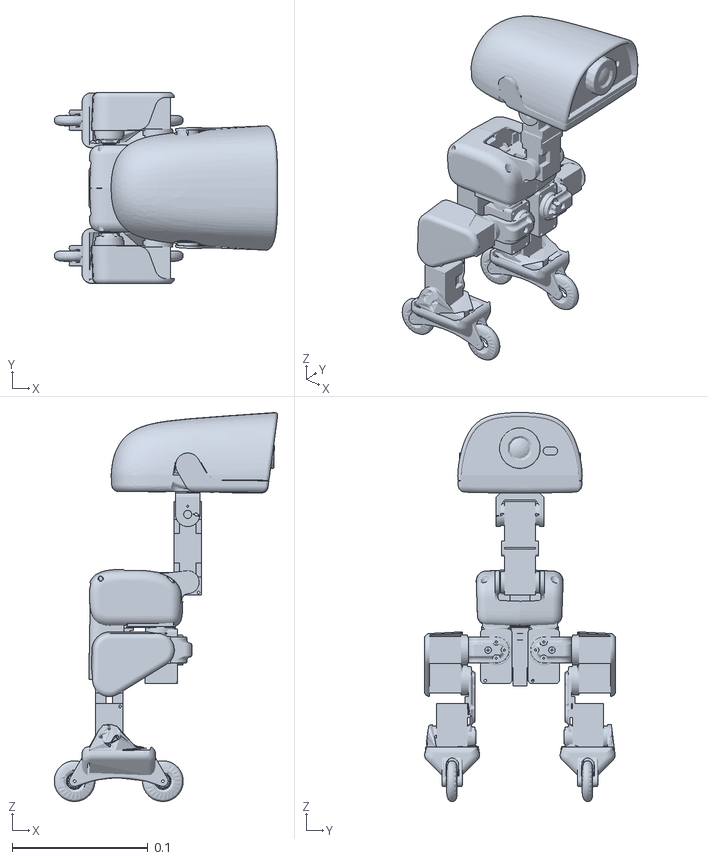
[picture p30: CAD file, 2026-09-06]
cad/microduck_combined_rollers.stl
0.165 x 0.141 x 0.286

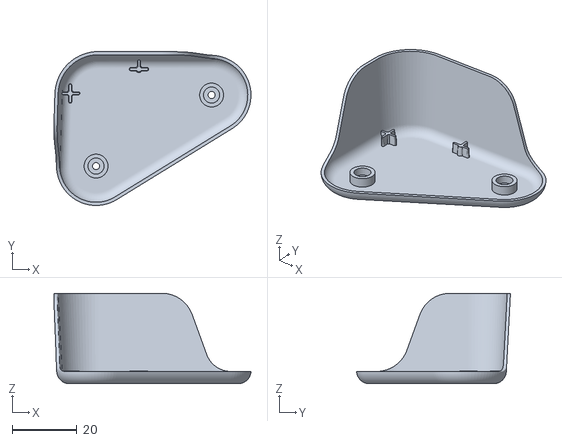
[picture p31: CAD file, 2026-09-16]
cad/parts/upper_leg_left.stl
61.0 x 47.7 x 28.0

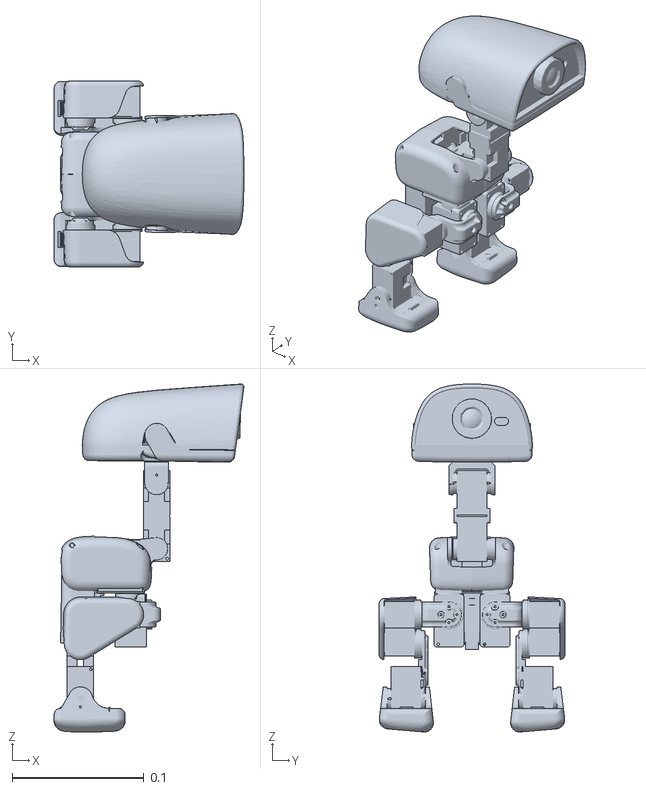
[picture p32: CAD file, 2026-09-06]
cad/microduck_combined.stl
0.144 x 0.141 x 0.264

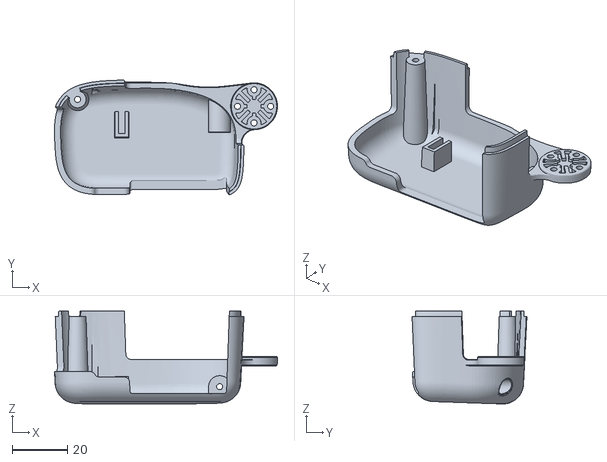
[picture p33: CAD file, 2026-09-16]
cad/parts/left_shell.stl
80.9 x 41.7 x 33.7

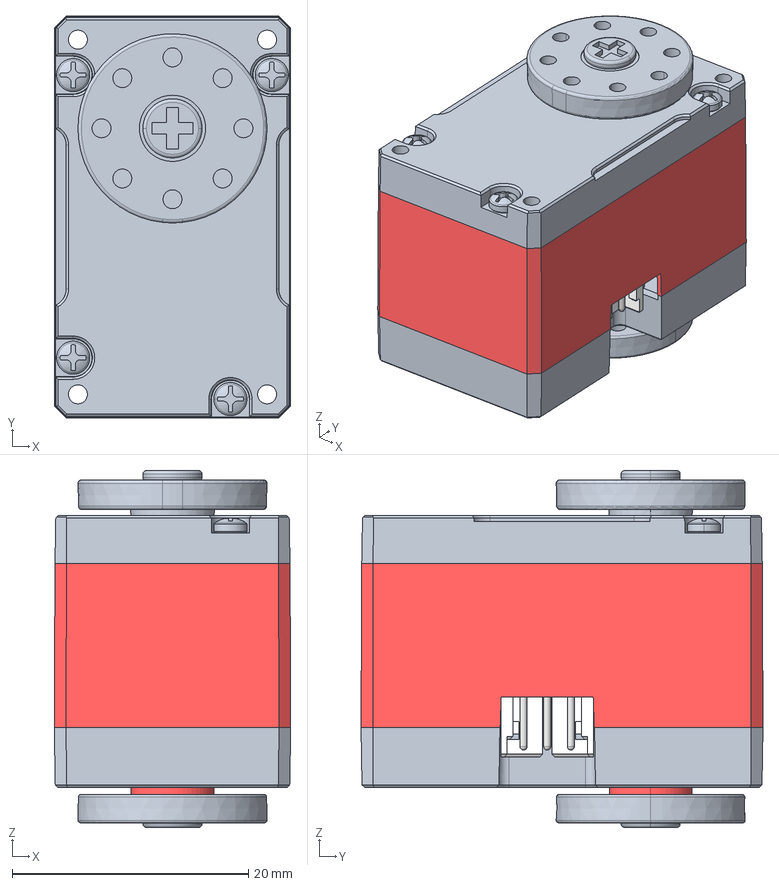
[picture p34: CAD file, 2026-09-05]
cad/HD-1910-C001-20260902.stp
20.0 x 34.0 x 30.2 mm
SJ-WK00-0140-MIDDLECASE_49
OUTPUTGEAR_1
AMP-3P-2_1 x 2
SJ-WK00-0138-TOPCABINET_6
SJ-WK00-0142-BOTTOMCASE_26
SJ-FDP0-0004-HORN_IDLE2_14
SJ-DP00-0003_HORN_7
PHS_1_7X20_5_DC10_3_1 x 4

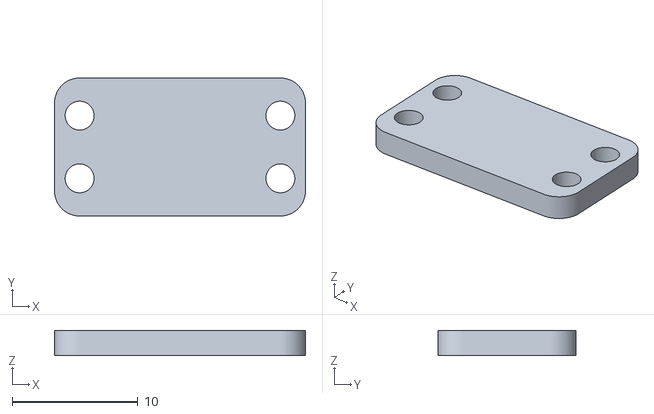
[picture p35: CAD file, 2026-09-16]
cad/parts/neck.stl
20.0 x 11.0 x 2.00

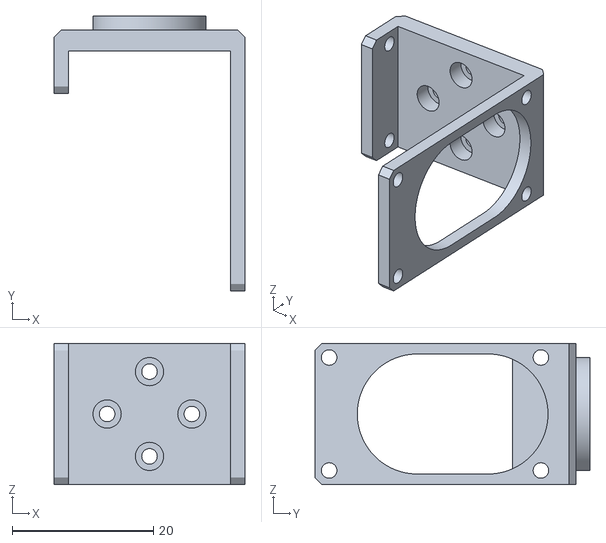
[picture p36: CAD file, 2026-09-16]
cad/parts/yaw2roll1.stl
27.0 x 39.0 x 20.0

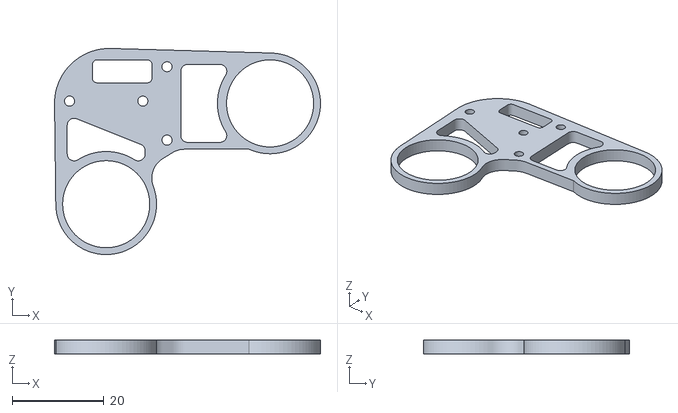
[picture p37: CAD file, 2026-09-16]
cad/parts/upper_leg_rigidity_plate.stl
58.1 x 45.0 x 3.00

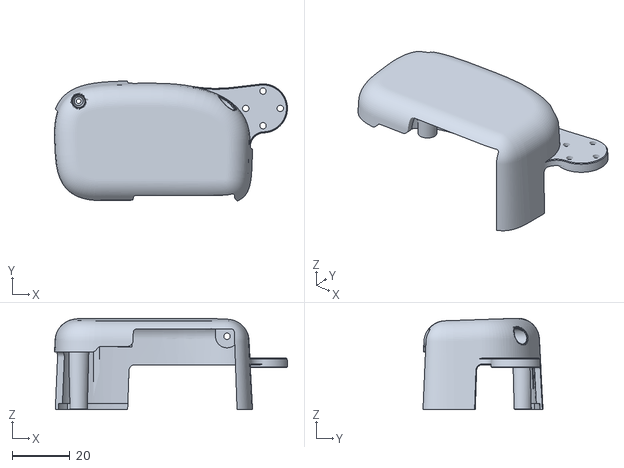
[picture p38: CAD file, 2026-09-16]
cad/parts/right_shell.stl
80.9 x 41.7 x 31.8

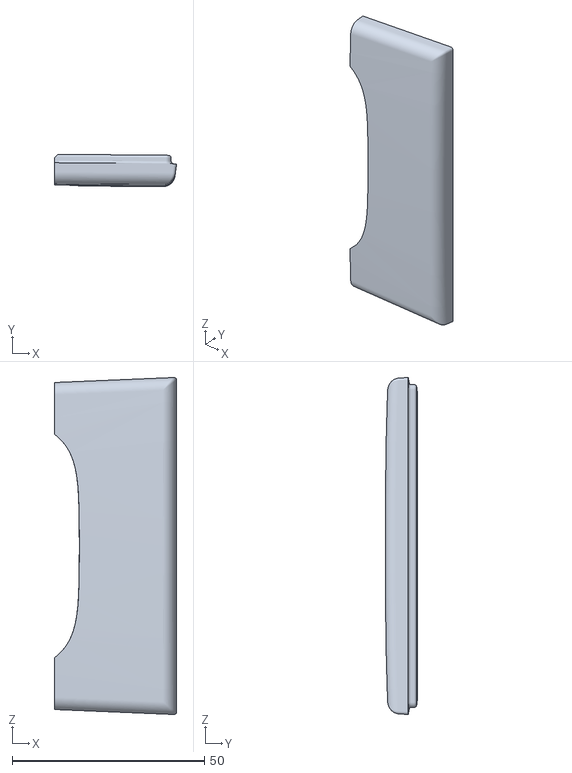
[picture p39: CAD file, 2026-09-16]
cad/parts/jaw_soft.stl
31.8 x 8.44 x 87.7

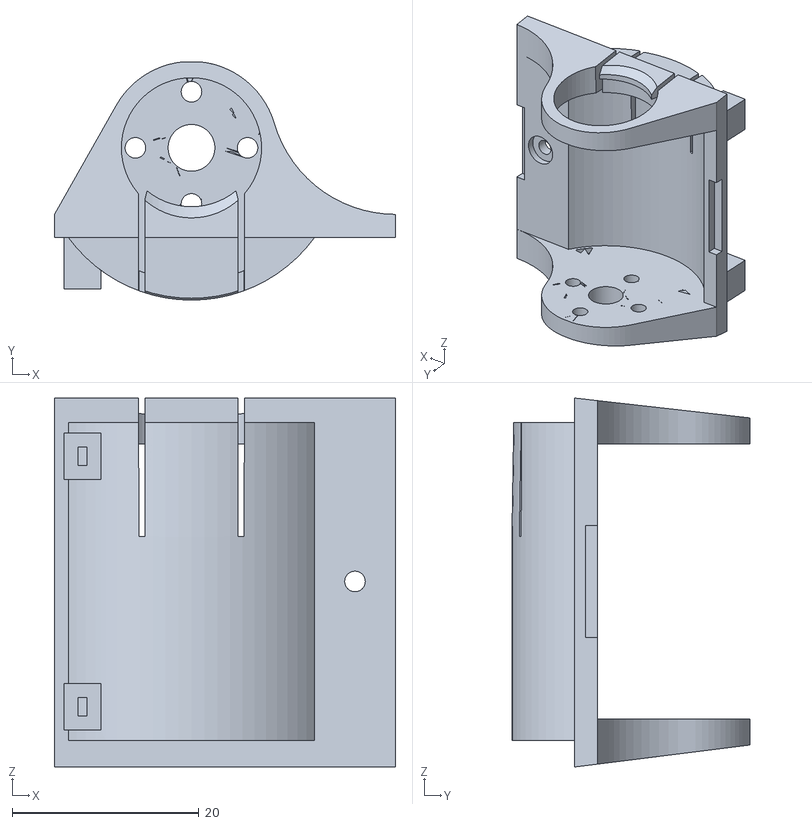
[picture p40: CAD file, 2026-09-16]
cad/parts/ankle_left.stl
36.5 x 25.5 x 39.5

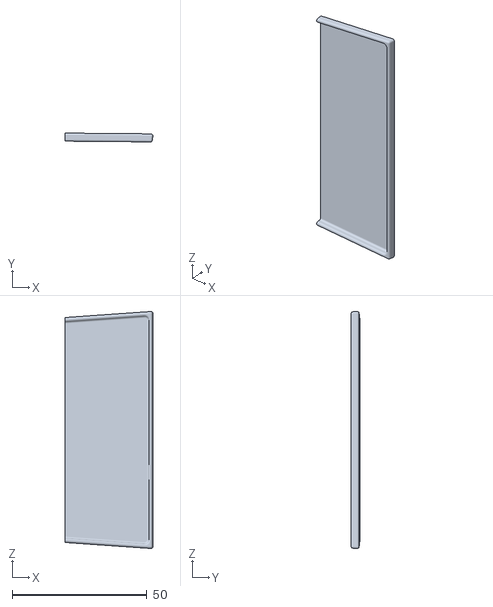
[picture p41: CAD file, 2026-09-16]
cad/parts/soft_mouth_top.stl
32.6 x 3.28 x 87.8

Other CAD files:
cad/parts/sole_right.stl
cad/parts/banana_pcb_locker.stl
cad/parts/hip_l1.stl
cad/parts/hip_l.stl
cad/parts/ankle_right.stl
cad/parts/bottom_head_shell.stl
cad/parts/face_part.stl
cad/parts/foot_left.stl
cad/parts/foot_right.stl
cad/parts/jaw.stl
cad/parts/leg.stl
cad/parts/leg2.stl
cad/parts/motor_support.stl
cad/parts/neck1.stl
cad/parts/neck_pitch.stl
cad/parts/noenoeil.stl
cad/parts/power_support.stl
cad/parts/top_head_shell.stl
cad/parts/trunk_base.stl
cad/parts/upper_leg_right.stl
cad/parts/upper_leg_rigidity_plate1.stl
cad/parts/yaw2roll.stl
cad/parts/yaw_roll_motion.stl

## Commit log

2026-09-04 增加群二维码
2026-09-04 添加装配文件
2026-09-04 添加部件文件
    [ankle_left.stl, ankle_right1.stl, banana_pcb_locker.stl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]
2026-09-04 更新图纸
    [ankle_left.stl, ankle_right1.stl, banana_pcb_locker.stl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]
2026-09-05 Add servo docs
    [HD-1910-C001-20260902.stp]
2026-09-06 Add standard assembly model (flat-foot)
    [microduck_combined.stl]
2026-09-06 Add roller-skating model
    [microduck_combined_rollers.stl]
2026-09-08 Update documentation. Add wiring diagram for servos.
2026-09-11 update stl models opt 0.1
    [ankle_left.stl, ankle_right1.stl, banana_pcb_locker.stl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]
2026-09-11 update stl models, opt0.1
    [ankle_left.stl, ankle_right1.stl, banana_pcb_locker.stl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]
2026-09-12 Rename imu_to_ft to the more generic imu_to_servo.
    The body IMU sits on the servo bus, so a Feetech-specific name was too narrow.
2026-09-15 Update the structure and provide explanations
    [ankle_left.stl, ankle_right.stl, ankle_right1.stl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]
2026-09-15 Update BOM and architecture
2026-09-16 Add detailed structural BOM and fix inconsistent descriptions across the docs.
2026-09-16 Restore BOM description.
2026-09-21 Update IMU module
2026-10-15 更新国庆训练视频和接线示意，并把舵机候选从伺泰威 ED330 换成伟创 RD05T。
    ET2216 按实际承重关节计 11 只，并注明另有 10 处轴承位不起支撑作用；舵机适配器改为 7.5V 6A。
2026-10-20 新增结构优化件（18650/21700 电池仓、左右外壳、电源支架）并更新 BOM 与 3mf 装配
2026-10-29 update: 在policies里更新了基础动作的模型权重
2026-10-29 update: README 改为只说明 5 个 ONNX，并固定 policies 换行为 LF
2026-10-29 update: 首页补上基础策略与预部署镜像，并同步英文 README 和硬件图标注
2026-11-03 update: policies 新增 sitstand 模型（trial-sitstand-14999 / model_14999）
2026-11-03 update: 更新了sitstand模型
2026-11-07 update: 首页换成新鞋试穿视频，并补上麦克风型号与舵机接线图
